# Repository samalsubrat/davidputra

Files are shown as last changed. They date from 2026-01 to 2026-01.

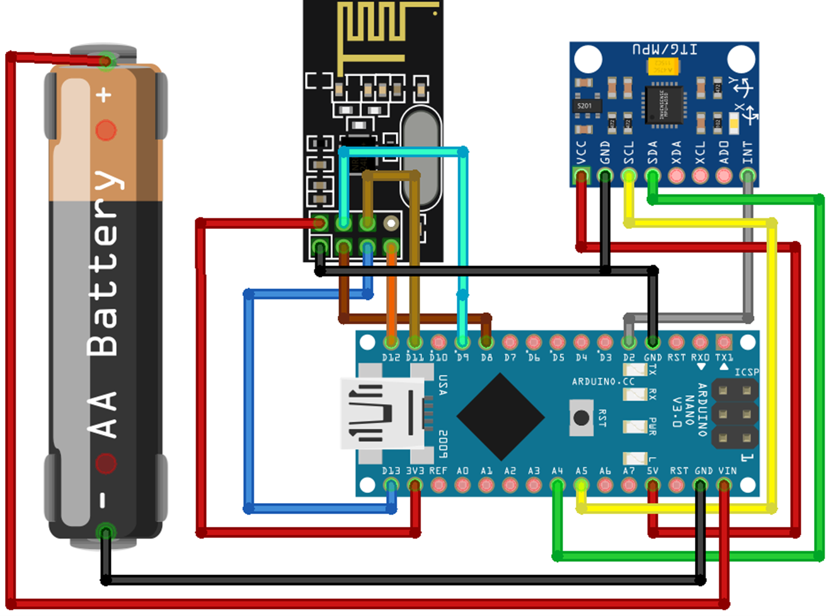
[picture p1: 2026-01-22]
Circuit Diagram/Transmitter.png

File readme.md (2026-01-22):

# Smart Wireless Robotic Vehicle 🚗🤖

A smart Arduino-based robotic vehicle that integrates **gesture control**, **mobile control**, **obstacle detection**, and **automotive-style LED feedback** using wireless communication and embedded systems.

---

## 📌 Project Overview

This project demonstrates a **smart wireless robotic vehicle** controlled using:
- A **gesture-based transmitter**
- **Bluetooth mobile control**
- Real-time **obstacle-aware safety logic**
- Dynamic **NeoPixel LED lighting effects**

The system is inspired by modern automotive behavior, focusing on **safety, responsiveness, and visual feedback**.

---

## 🧠 System Architecture

The project consists of two main units:

### 1️⃣ Transmitter Unit
- Arduino Nano
- MPU6050 (gesture sensing)
- NRF24L01 (wireless transmission)

### 2️⃣ Receiver Unit
- Arduino Uno
- NRF24L01 (wireless reception)
- HC-05 Bluetooth module (mobile control)
- TB6612FNG motor driver
- Ultrasonic sensor (HC-SR04)
- NeoPixel RGB LED strip

---

## ⚙️ Key Features

- Gesture-based control using MPU6050
- Mobile phone control via Bluetooth
- Dual wireless input (NRF + Bluetooth)
- Obstacle-aware forward movement
- Free backward and turning motion
- Automotive-style LED indicators
- RGB flowing effect during reverse
- Non-blocking real-time operation

---

## 🚦 Control Logic

| Command | Action |
|---|---|
| `W` | Move Forward |
| `S` | Move Backward |
| `A` | Turn Left |
| `D` | Turn Right |
| `X` | Stop |

- Obstacle detection is applied **only during forward movement**
- Backward motion is always allowed

---

## 💡 Lighting Behavior (NeoPixel)

- **White center LEDs** → Normal operation
- **Orange sliding indicators** → Left / Right turns
- **RGB flowing effect** → Backward movement
- **All LEDs OFF** → Stop state

---

## 🛡️ Safety Mechanism

- Front-mounted ultrasonic sensor continuously measures distance
- Automatically stops the vehicle when an obstacle is detected in front
- Prevents collision without blocking reverse or turning actions

---

## 🔧 Technologies Used

- Arduino Uno & Nano
- C / C++ (Arduino framework)
- NRF24L01 Wireless Module
- HC-05 Bluetooth Module
- MPU6050 Sensor
- HC-SR04 Ultrasonic Sensor
- TB6612FNG Motor Driver
- Adafruit NeoPixel Library

---

## 🚀 Applications

- Smart robotics
- Gesture-controlled systems
- Autonomous vehicle prototypes
- Embedded systems learning
- Automotive electronics simulation

---

## 🔮 Future Enhancements

- Rear obstacle detection
- Mobile app-based UI
- Brake and hazard lighting logic
- Speed-based LED animations
- ESP32-based implementation

---

## 🎥 Project Demonstration Video

📽️ **Watch the complete working demo here:**  
👉 *[Click Here](https://youtu.be/7BjSHVF1QDA)*

Figma Link: [Click Here](https://www.figma.com/design/feEBxf5zE0kvkO5WWOrKDI/David-Putra-Presentation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)

---

## 🙌 Acknowledgements

This project was developed as part of an academic embedded systems and robotics initiative, demonstrating real-time control, sensing, and wireless communication.

---

## 📬 Contact

For questions or collaboration, feel free to reach out.

---

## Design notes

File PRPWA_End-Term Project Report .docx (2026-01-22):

Project Title

End-Term Project Report

For

Practical Robotics Projects with Arduino (CSE 4571)

Submitted by

Subrat Samal | 2241019269
Saswat Sharma | 2241019415
Shashwat Sahoo | 2241019128
Arvind Naik | 2241014005
Abhinandana Sahoo | 2241019022
Bikash Mallick | 2241013070

B. Tech. 7th Semester, CSE

Project Supervisor

Dr. Hara Prasad Tripathy | (Associate Professor/Assistant Professor)

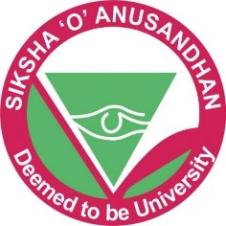
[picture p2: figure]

DEPARTMENT OF COMPUTER SCIENCE AND ENGINEERING

Institute of Technical Education and Research

SIKSHA ‘O’ ANUSANDHAN DEEMED TO BE UNIVERSITY

Bhubaneswar, Odisha, India.

(January, 2026)

# DECLARATION

We certify that

a. The work contained in this report is original and has been done by us under the guidance of our supervisor.
b. The work has not been submitted to any other Institute for any degree or diploma.
c. We have followed the guidelines provided by the Department in preparing the report.

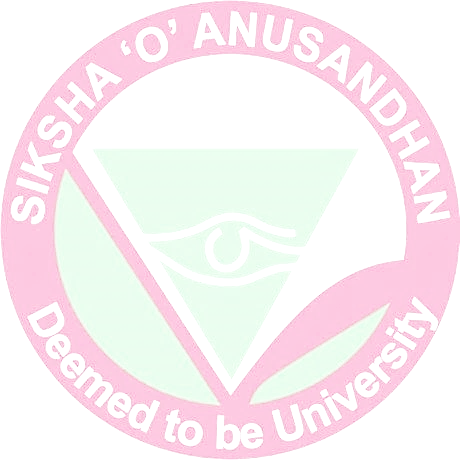
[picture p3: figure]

d. Whenever we have used materials (data, theoretical analysis, figures, and text) from other sources, we have given due credit to them by citing them in the text of the report and giving their details in the reference.

Name of the Student | Registration Number | Signature
Subrat Samal | 2241019269
Arvind Naik | 2241014005
Shashwat Sahoo | 2241019128
Saswat Sharma | 2241019415
Abhinandana Sahoo | 2241019022
Bikash Mallick | 2241013070

# REPORT APPROVAL

The report entitled

TITLE OF THE PROJECT

by

Subrat Samal | 2241019269
Arvind Naik | 2241014005
Shashwat Sahoo | 2241019128
Saswat Sharma | 2241019415
Abhinandana Sahoo | 2241019022
Bikash Mallick | 2241013070

is approved for

Practical Robotics Projects with Arduino (CSE 4571)

in

Computer Science and Engineering

Supervisor’s Name
Date:
Place:

# CONTENTS

# ABSTRACT

This project presents the design and development of a Gesture Controlled Robot Car using Arduino, integrating embedded systems, wireless communication, and human–robot interaction. The system is built around an Arduino Uno microcontroller that controls a four-wheel-drive robotic vehicle capable of responding to real-time gesture-based commands. Wireless communication is achieved using the NRF24L01 module, while obstacle detection is handled by ultrasonic sensors to enhance safety and autonomy.

The robotic car employs a TB6612FNG motor driver for efficient motor control and NeoPixel LEDs for visual feedback. Gesture inputs captured through sensors are translated into movement commands such as forward, backward, left, right, and stop. This project demonstrates an intuitive and user-friendly approach to controlling robotic vehicles and highlights the growing importance of intelligent and interactive robotic systems in modern applications.

# Chapter 1: Introduction

### 1.1. Motivation

With rapid advancements in robotics and embedded systems, there is a growing demand for intelligent machines capable of interacting naturally with humans. Gesture-controlled systems provide an intuitive alternative to conventional control mechanisms such as switches or joysticks. This project is motivated by the need to develop an interactive robotic vehicle that combines gesture control, wireless communication, and autonomous sensing to improve usability and responsiveness.

### 1.2. Design Goals

#### 1.2.1 Purpose

The purpose of this project is to design and implement a gesture-controlled robotic car that can be wirelessly operated and perform basic autonomous functions such as obstacle detection.

#### 1.2.2 Scope

The scope of the project includes embedded control using Arduino, wireless data transmission, real-time motor control, and sensor-based obstacle avoidance.

#### 1.2.3 Applicability

Such robotic systems can be applied in areas like surveillance, defense, warehouse automation, research, and educational robotics.

### 1.3. Problem Statement

Traditional robotic vehicles often rely on manual controls or fixed programming logic, limiting their adaptability and ease of use. The lack of intuitive human–robot interaction makes them unsuitable for dynamic environments. This project addresses this limitation by introducing gesture-based wireless control, enabling real-time, flexible, and user-friendly operation.

### 1.4. Organization of the Report

This report is organized into nine chapters covering introduction, literature survey, design scheme, testing, socio-economic aspects, tools and standards, challenges, teamwork, and conclusions.

# Chapter 2: Literature Survey

### 2.1. Background work done so far

Previous research in mobile robotics has focused on joystick-controlled, Bluetooth-controlled, or autonomous robotic cars. Gesture-controlled robotics has emerged as an advanced method of interaction, offering hands-free and natural control. Studies show that combining wireless communication with sensor-based autonomy significantly improves robot efficiency and safety. However, many existing systems are either costly or complex, motivating the development of a low-cost Arduino-based solution.

# Chapter 3: Design Scheme

### 3.1. System Design

The system consists of a gesture input unit, wireless communication module, Arduino-based control unit, motor driver circuit, ultrasonic sensors, and visual feedback components.

### 3.2. Architecture

Gesture data is captured and transmitted wirelessly to the robotic car. The Arduino Uno processes the received commands and controls the motors accordingly while continuously monitoring obstacle distance using ultrasonic sensors.

### 3.3. Component Design

· Arduino Uno: Central controller

· Arduino Nano: Transmitter controller

· TB6612FNG Motor Driver: Controls motor direction and speed

· DC BO Motors & Wheels: Enable vehicle movement

· HC-SR04 Ultrasonic Sensor: Obstacle detection

· NRF24L01 Module: Wireless communication

· NeoPixel LEDs: Visual status indication

### 3.4. Implementation

The system is implemented using embedded C/C++ programming on Arduino. Gesture commands are mapped to predefined motor actions. Sensor data is continuously monitored to ensure obstacle avoidance.

### 3.5. Design Evolution

Initially designed as a simple remote-controlled car, the system evolved to include gesture recognition, wireless control, visual feedback, and autonomous obstacle detection.

# Chapter 4: Testing, Analysis, and Evaluation

### 4.1. Testing Criterions

4.1.1. Relevance

The functionality of each module was tested to verify that it performs the intended task. Input and output behavior was checked to confirm correct responses under expected conditions. The system’s output was compared with the expected results to ensure accuracy. Real-world use cases were simulated to validate practical applicability.

4.1.2. Effectiveness

The system was tested for correct operations and response accuracy. We conducted multiple test runs to ensure consistent behavior. We checked sensor readings and actuator responses for precision. Wireless communication is stable, and obstacle detection works reliably within defined distance thresholds.

4.1.3. Efficiency

Execution time of the system was measured. Memory and processing utilization were checked. The motor driver ensures efficient power usage, and the system operates smoothly with minimal latency.

# Chapter 5: Socio-Economic Issues associated with the Project

### 5.1. Detailed Cost Analysis

#### 5.1.1. Cost Analysis

The project is designed using low-cost, readily available components. Maintenance cost is low because of the modular design. The system is budget-friendly for students and small-scale users.

#### 5.1.2. Bill of Materials

COMPONENT APPROX COST Arduino Uno Rs 250 Arduino Nano Rs 200 TB6612FNG Rs 200 DC Geared motors Rs 300 Wheels Rs 200 18650 Batteries Rs 240 Battery Holder Rs 50 NRF24L01 HC-SR04 Rs 250 Rs 120 | COMPONENT APPROX COST MPU6050 Rs 180 HC-05 Rs 220 WS2812B NeoPixel Light Rs 300 3D printed Chasis Rs 550 Wires & Other Parts Rs 1000 Total Rs 4060

### 5.2. Safety issues

Low-voltage operation ensures user safety. We used proper insulation to prevent short circuits. We tested moving parts to avoid mechanical hazards. We avoided overcurrent and overheating conditions. Obstacle detection and controlled motor speed reduce the risk of collision and hardware damage.

### 5.3. Global Impact

Gesture-controlled robotics can improve automation, reduce human effort, and support innovation in smart systems globally. It encourages uses of embedded system and robotics. It can also be scaled for industrial, healthcare, or environmental applications.

### 5.4. Lifelong Learning

The project enhances hands-on learning in embedded systems, robotics, wireless communication. It improves problem-solving and debugging skills. It encourages self-learning and innovation and promotes continuous learning as well as skill development.

# Chapter 6: Engineering Tools and Standards used in the Project

• Arduino IDE

• Visual Studio Code

• Fusion 360

• Embedded C/C++

• Standard electronic components

• IEEE standards for wireless communication (NRF24L01)

# Chapter 7: Problems, faults, bugs, challenges

### 7.1. Problems

### Initially there was difficulty in understanding how components connect and interact. Power supply was unstable during early testing. There were integration issues between hardware and software modules. Time constraints occurred during implementation.

### 7.2. Faults

The pin configuration was incorrect in the early stages. Loose connections were causing intermittent failures. There were errors in sensor calibration.

### 7.3. Bugs

There were logical errors in program flow. Incorrect delay timings affected system response. Code synchronization issues occurred between transmitter and receiver.

### 7.4. Challenges

It was challenging to synchronize multiple components without problems, achieving stable and reliable connections between transmitter and receiver. Integrating gesture control with real-time obstacle avoidance also proved to be a hard task.

# Chapter 8: Teamwork

### 8.1. Summary of team work

### 8.1.1 Attributes

1 | Attends group meetings regularly and arrives on time.
2 | Contributes meaningfully to group discussions.
3 | Completes group assignments on time.
4 | Prepares work in a quality manner.
5 | Demonstrates a cooperative and supportive attitude.
6 | Contributes significantly to the success of the project.

### 8.1.2 Score

1=strongly disagree; 2=disagree; 3=agree; 4=strongly agree

Student 1: _________________ Student 2: _________________

Student 3: _________________ Student 4: _________________

Student 5: _________________ Student 6: _________________

Student 1 | Evaluated by
| Attributes | Student 1
| 1
| 2
| 3
| 4
| 5
| 6
| Grand Total

Student 2 | Evaluated by
| Attributes | Student 2
| 1
| 2
| 3
| 4
| 5
| 6
| Grand Total

Signature of Student 1 | | Signature of Student 2

# Chapter 8: Teamwork

Student 1 | Evaluated by
| Attributes | Student 3
| 1
| 2
| 3
| 4
| 5
| 6
| Grand Total

Student 2 | Evaluated by
| Attributes | Student 4
| 1
| 2
| 3
| 4
| 5
| 6
| Grand Total

Signature of Student 3 | | Signature of Student 4

Student 1 | Evaluated by
| Attributes | Student 5
| 1
| 2
| 3
| 4
| 5
| 6
| Grand Total

Student 2 | Evaluated by
| Attributes | Student 6
| 1
| 2
| 3
| 4
| 5
| 6
| Grand Total

Signature of Student 5 | | Signature of Student 6

# Chapter 9: Conclusion

The Gesture Controlled Robot Car successfully demonstrates a gesture-based transmitter using Arduino Nano, MPU6050, and NRF24L01 to generate intuitive control commands. The project also demonstrates the practical application of theoretical concepts learned during the course. The project was designed, implemented and tested systematically to meet stated objectives.

Throughout the development process, careful attention was given to system design, component selection, and implementation. All major modules functions as intended and the system meets the required performance standards.

The project also considers key social and economic factors like cost effectiveness, safety, and global impact. By using low-cost and readily available components, the system is economically viable. Safety measures were included to guarantee secure operation and the project positively contributes to technological development and automation.

In conclusion, the project fulfills its objectives by combining gesture-based control, obstacle detection, and embedded automation. It provides a strong foundation for future enhancements such as AI-based navigation and advanced gesture recognition.

# References

[1] Ian Goodfellow, Jean Pouget-Abadie, Mehdi Mirza, Bing Xu, David Warde-Farley, Sherjil Ozair, Aaron Courville, and Yoshua Bengio. Generative adversarial nets. In Z. Ghahramani, M. Welling, C. Cortes, N. D. Lawrence, and K. Q. Weinberger, editors, Advances in Neural Information Processing Systems 27, pages 2672{2680. Curran Associates, Inc., 2022. URL http://papers.nips.cc/paper/5423-generative-adversarial-nets.pdf

# Appendix

• Circuit connections

• Source code

• Additional test results

• Bill of Materials: https://docs.google.com/spreadsheets/d/1gfLWkVbYy9ZIcscaKPQqSDvCIqm1ycbmBt-wKWR98AM/edit?usp=sharing

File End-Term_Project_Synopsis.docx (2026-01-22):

Group No. | Group Members (Regd. No.) | Project Title
12 | 2241019269 | David Putra - Gesture Controlled Robot Car Using Arduino
| 2241014005
| 2241019128
| 2241019415
| 2241013070
| 2241019022

Fill up the following Topics and submit the colour printed Hardcopy to the corresponding Faculties.

1. Introduction: (Details about the Topic, industry, products, need of study and some history about the same etc.)

This project entails the construction of a 4WD robotic car that integrates embedded systems and modern wireless communication to achieve intelligent mobile robotics behavior. With the growing demand for autonomous and remotely controlled systems, such robotic platforms are increasingly relevant in applications such as autonomous vehicles, logistics, military operations, and research. This project focuses on the integration of mobile robotic systems at the control level of a robotic vehicle, demonstrating the vehicle’s responsive behavior and user interactivity.

The robotic car uses an Arduino Uno microcontroller as its central control unit. The microcontroller performs control functions for the car’s hardware, including motor control through a TB6612FNG motor driver and autonomous obstacle detection using an HC-SR04 ultrasonic sensor. The robotic car also features a NeoPixel LED strip to provide visual feedback and an NRF24L01 wireless module to enable wireless communication.

A key feature of this project is the gesture control system, which allows the user to control the robotic car through hand gestures. These gestures are captured and translated into control commands such as “move forward,” “turn left,” or “stop.” The commands are transmitted wirelessly to the microcontroller, which then executes the corresponding actions, enabling real-time remote control and intuitive interaction with the robotic vehicle.

The research initiated to fulfill the demand for intelligent, autonomous, and human-interactive systems in robotics.

2. Problem identification and Problem Formulation: (Core area of problems or other related problems and their brief solutions)

Conventional robotic vehicles can either be driven manually or have their actions determined through preset logic, resulting in limited flexibility and reduced human interaction. Since these systems lack intuitive control mechanisms, they are less effective in dynamic and real-time environments. The principal challenge lies in achieving responsive and user-friendly control of embedded robotic systems. This project addresses the challenge using an Arduino-based control system combined with a gesture-controlled wireless interface, allowing the user to command the robotic vehicle to move, avoid obstacles, and respond effectively in real time. This approach enhances human–robot interaction while maintaining reliable and efficient embedded control.

3. Objective of the Project: (Objectives should be mentioned pointwise. Students can also divide the broader and narrow areas of the objectives. These objectives must be near to the situation of the problems)
- To design and build a 4WD robotic car using Arduino and essential hardware components.
- To implement autonomous obstacle detection using the HC-SR04 sensor.
- To add AI control through an Android app that understands voice/text commands.
- To enable wireless communication using the NRF24L01 module.
- To control the car's movement using the TB6612FNG motor driver.
- To provide visual feedback using a NeoPixel LED strip.
- To develop a user-interactive robotic system that responds to natural commands.
4. Block Diagram of the Project: (Diagram of a system in which the principal parts or functions are represented by blocks connected by lines that show the relationships of the blocks)

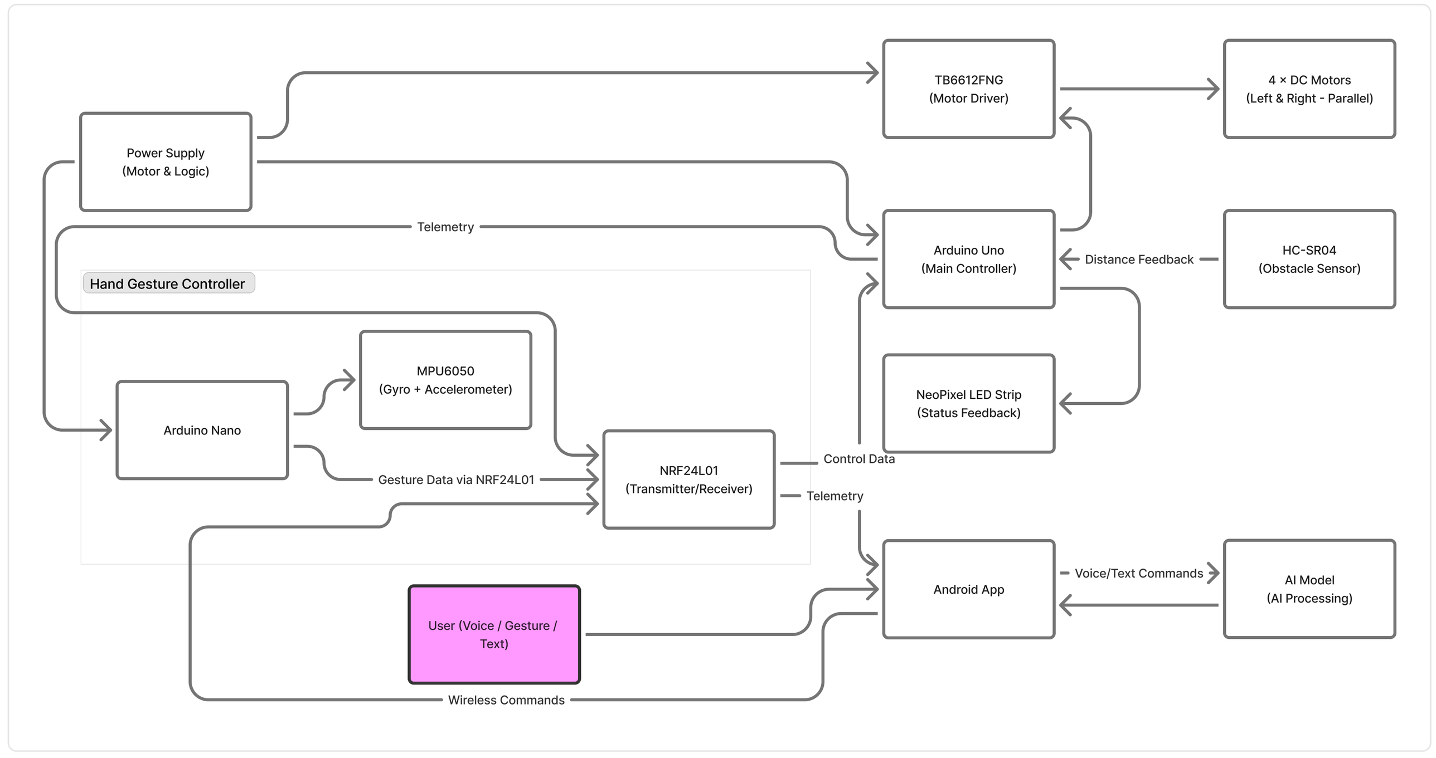
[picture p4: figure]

5. Circuit Diagram of the project:

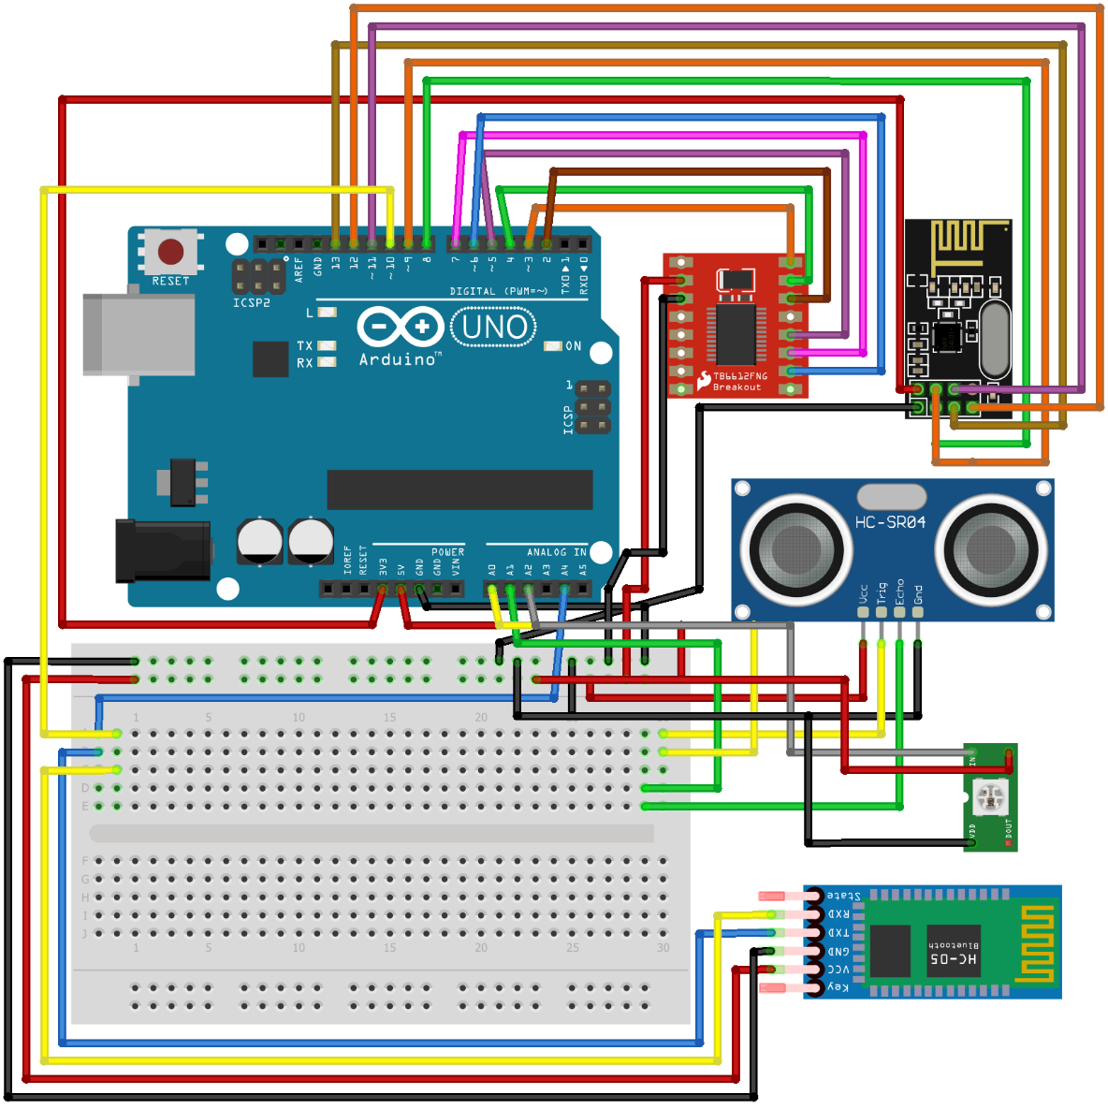
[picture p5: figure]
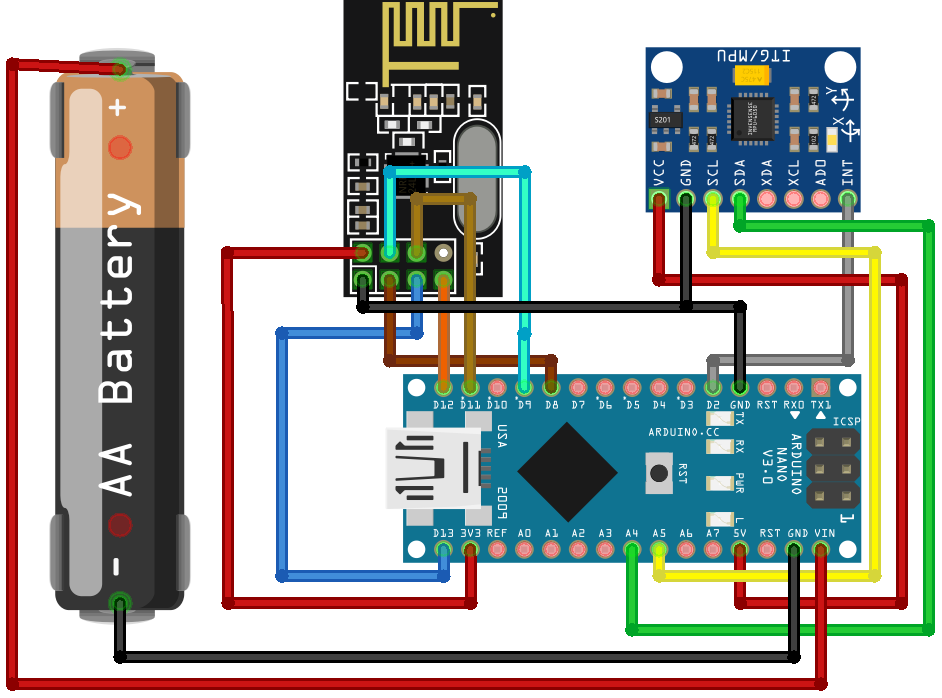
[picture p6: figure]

6. Components/Items Required:

Sl. No. | Name of the Components | Specification | Quantity
1 | Arduino UNO | ATmega328P, 16 MHz | 1
2 | TB6612FNG Motor Driver | Motor Driver Carrier | 1
3 | DC BO Gear Motor | 500 RPM Straight | 4
4 | Wheels | 65mm | 4
5 | Battery | Lipo – 2200mAh-18650 | 3
6 | Battery Holder with Switch | On/Off switch | 2
7 | MPU6050 | Accelerometer + Gyro | 1
8 | Bluetooth Module | HC-05 Module | 1
9 | Arduino Nano | ATmega328P, 16 MHz | 1
10 | Ultrasonic Sensors | HC-SR04 | 2
11 | WiFi Transceiver | NRF24L01 | 2
12 | NeoPixel Lights | WS2812 | 16
13 | Jumper Wires and Accessories | Connecting | -

The project synopsis should be verified by the corresponding faculties within 7 days.

Signature of Corresponding Faculty

Full Signature of Group members:

1.

2.

3.

4.

5.

6.

Practical Robotics Projects with Arduino End-Term Project Synopsis

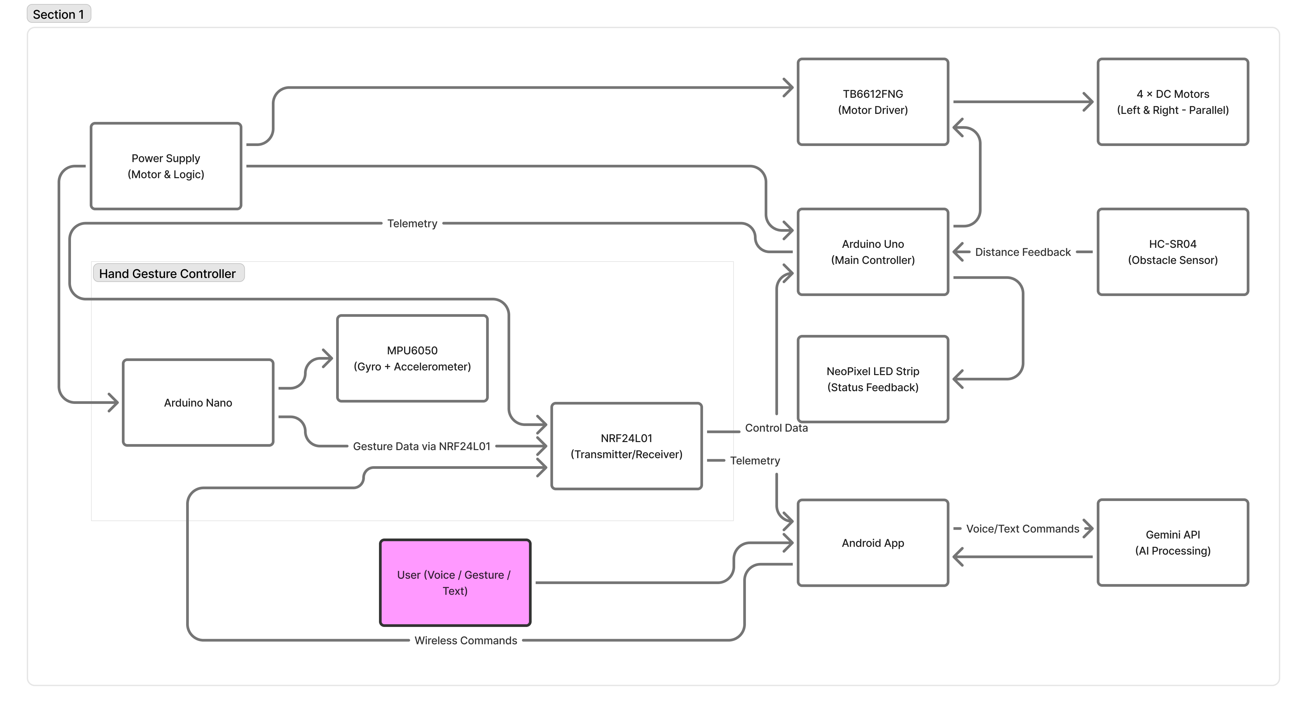
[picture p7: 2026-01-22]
Circuit Diagram/Block Diagram.png

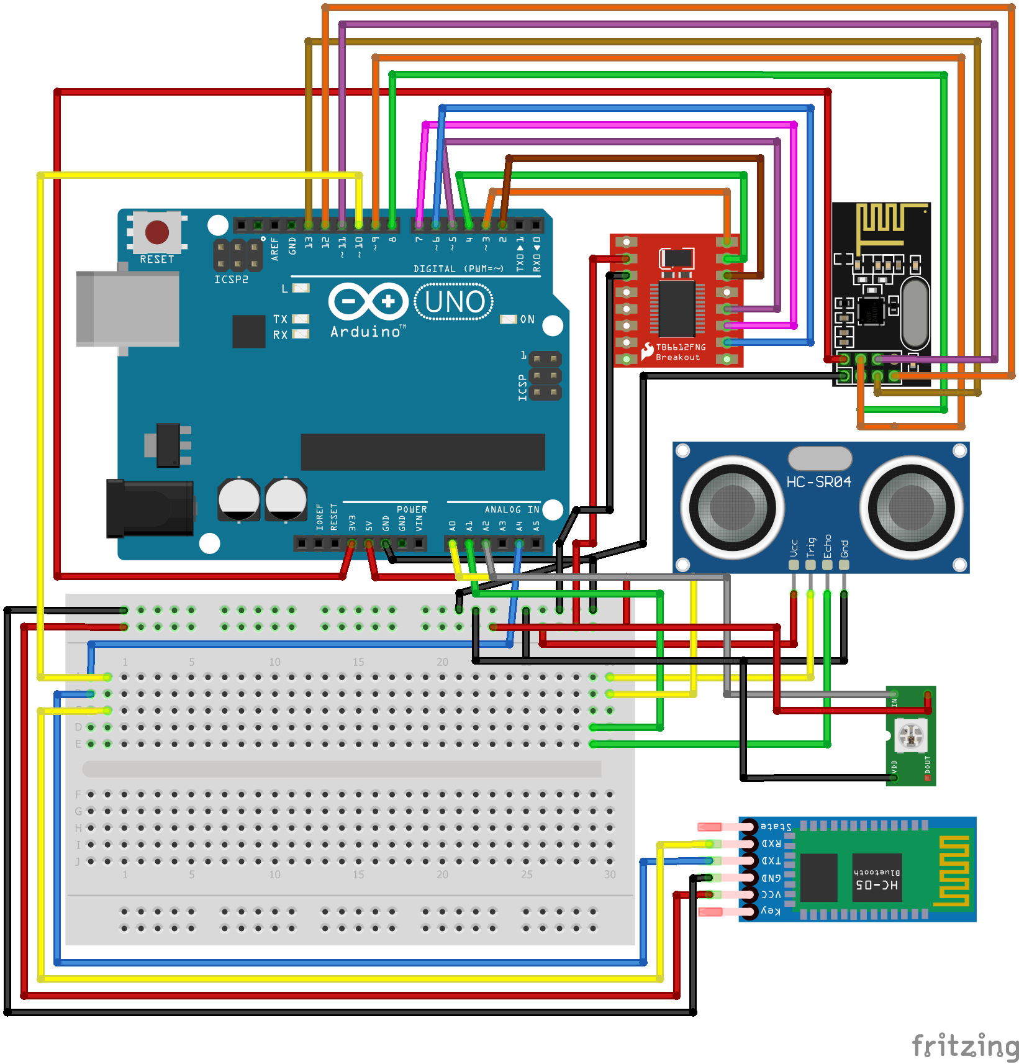
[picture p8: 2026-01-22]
Circuit Diagram/receiver_bb.png

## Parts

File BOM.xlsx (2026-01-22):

Component | Qty | Description / Notes | Price (INR) | Sub Total
Arduino Uno | 1 | Main controller for the car | 250 | 250
TB6612FNG Motor Driver | 1 | Dual motor driver (4 BO motors via both channels) | 165 | 165
500 RPM DC BO GEAR MOTOR STRAIGHT | 4 | DC gear motors (cheap & lightweight) | 75 | 300
Wheels (65mm or 70mm) | 4 | Compatible with BO motors | 25 | 100
Hongli 2200mAh 18650 | 3 | 7.4V–11.1V supply for motors and Uno | 80 | 240
Battery Holder with Switch | 2 | Power management | 50 | 100
MPU6050 or MPU9250 | 1 | Accelerometer + Gyro (gesture input) | 200 | 200
HC-05 Bluetooth Module (for car) | 1 | Bluetooth receiver for control | 250 | 250
Arduino Nano(for glove/controller) | 1 | Processes MPU6050 and sends gestures | 200 | 200
HC-05 Bluetooth Module (for glove) | 1 | Sends control data to car | 250 | 250
Glove | 1 | To mount MPU6050 for gesture input | 50 | 50
Jumper Wires / Connectors / Header Pins | 1 | For connections and soldering | 100 | 100
Breadboard / Custom PCB | 1 | For organized wiring | 100 | 100
HC-SR04 | 4 | UltraSonic Sensor | 60 | 240
PAM8403 Amp | 1 | Amplifier for the speaker | 35 | 35
Speaker | 1 | For AI | 40 | 40
NeoPixel Lights | 2 | Aesthetics | 150 | 300
Camera Module OV7670 | 1 | Camera | 169 | 169
NRF24L01 | 2 | Wireless Stuff | 100 | 200
3D Printing | 1 | Chasis | 550 | 550
Other stuff | 1 | Capacitors, resistors | 200 | 200
 |  | Total |  | 4039

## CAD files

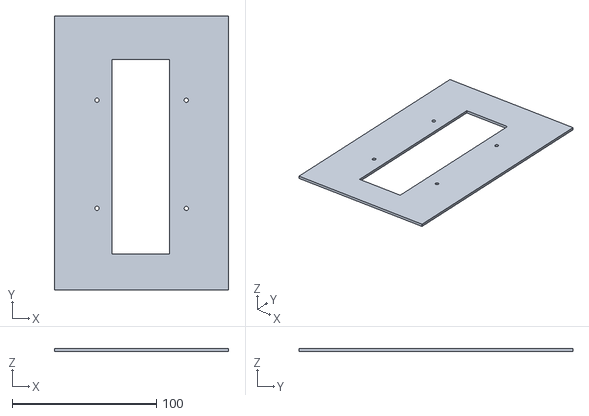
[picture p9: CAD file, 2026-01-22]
3d Files/Chassis bottom.stl
121.0 x 190.0 x 2.00

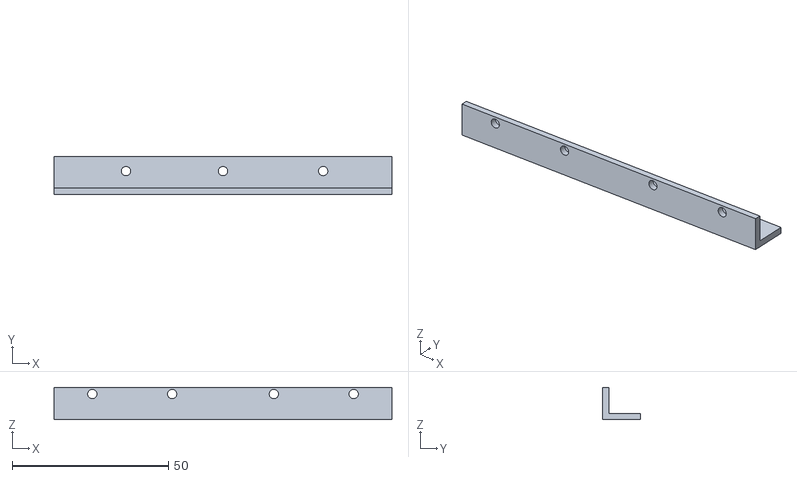
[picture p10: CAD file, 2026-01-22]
3d Files/light bracket.stl
108.0 x 12.0 x 10.4

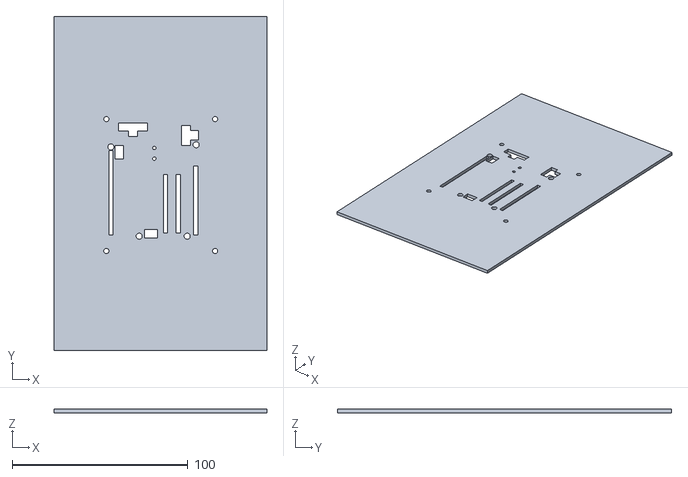
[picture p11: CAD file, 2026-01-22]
3d Files/Chassis top.stl
121.0 x 190.0 x 2.00

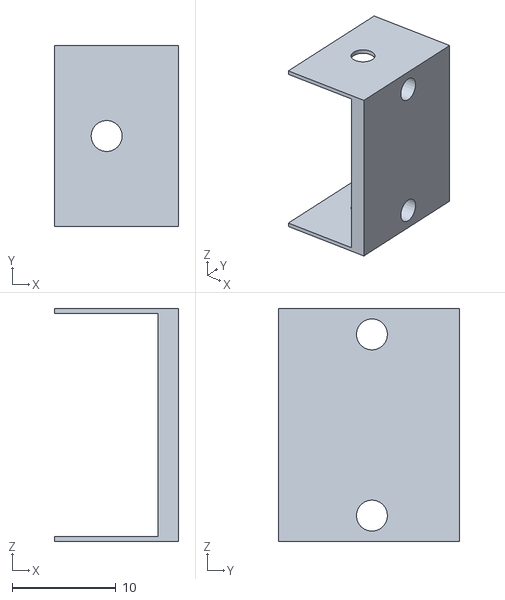
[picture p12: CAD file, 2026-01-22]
3d Files/motor holder.stl
12.0 x 17.4 x 22.5

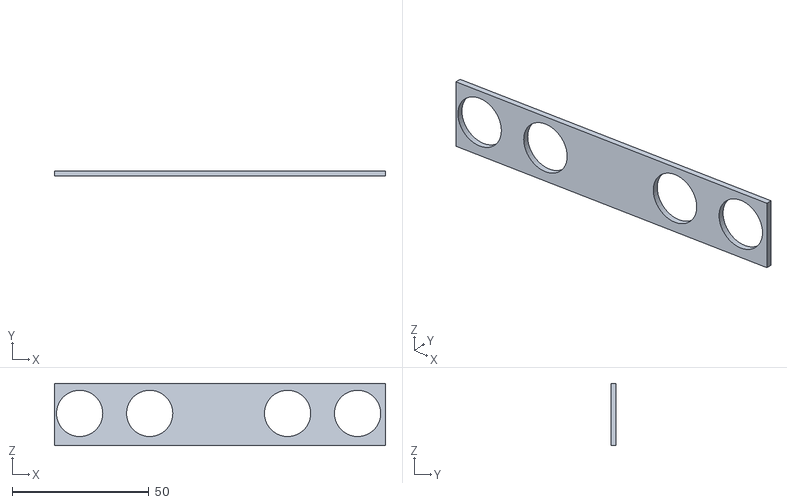
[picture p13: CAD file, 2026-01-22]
3d Files/ultrasonic holder.stl
121.0 x 2.00 x 22.8

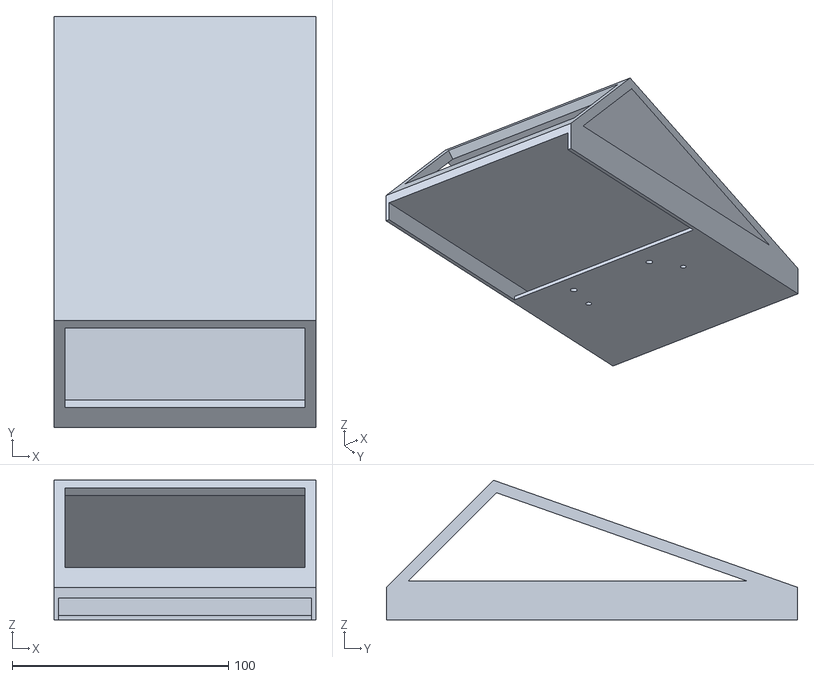
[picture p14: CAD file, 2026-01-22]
3d Files/Top Frame.stl
121.0 x 190.0 x 64.5

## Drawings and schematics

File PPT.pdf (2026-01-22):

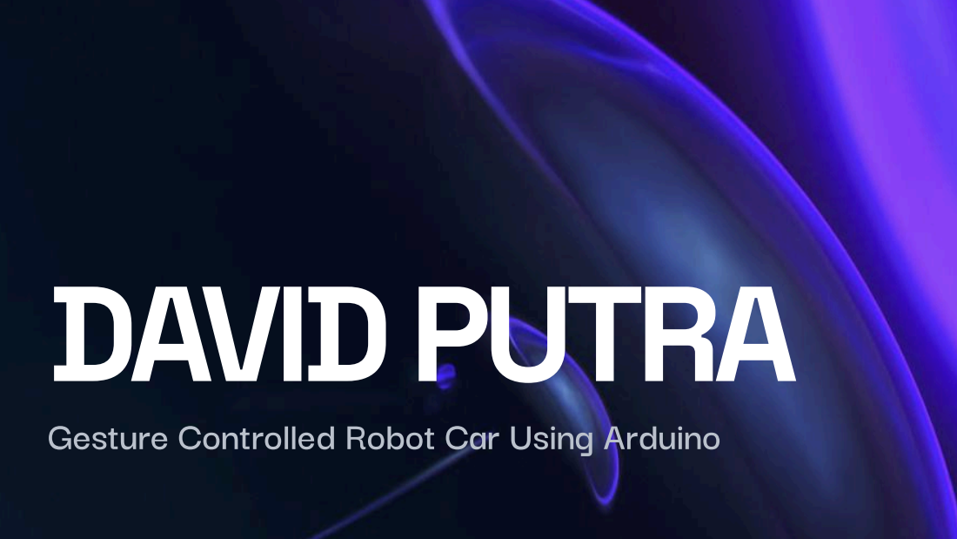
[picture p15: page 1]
David putra

Gesture Controlled Robot Car Using Arduino

# THE

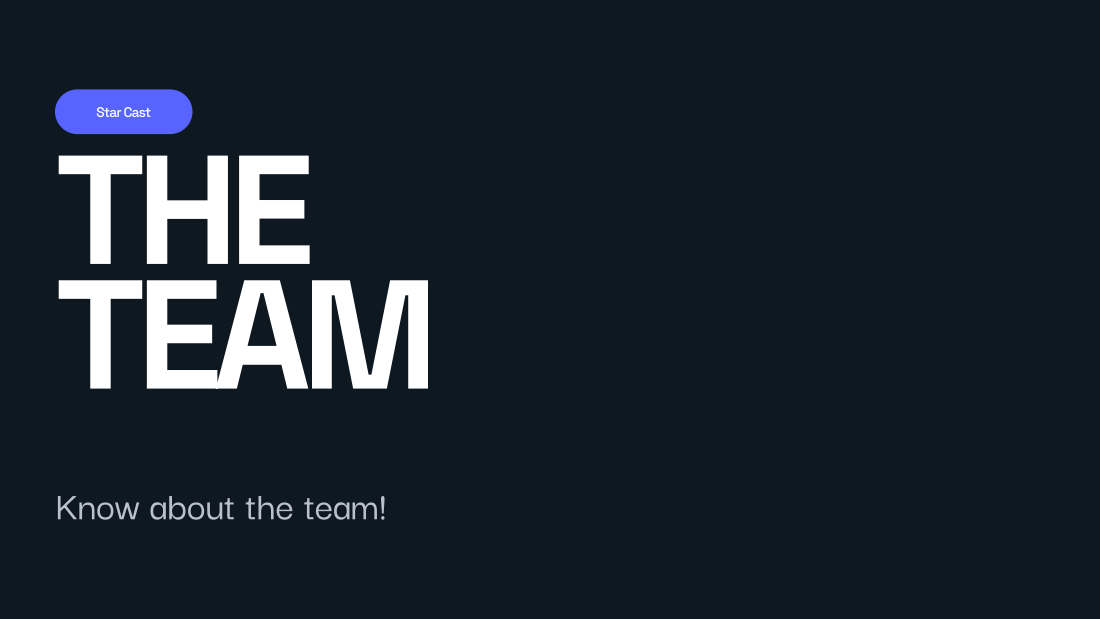
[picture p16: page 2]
Star Cast TEAM

Know about the team!

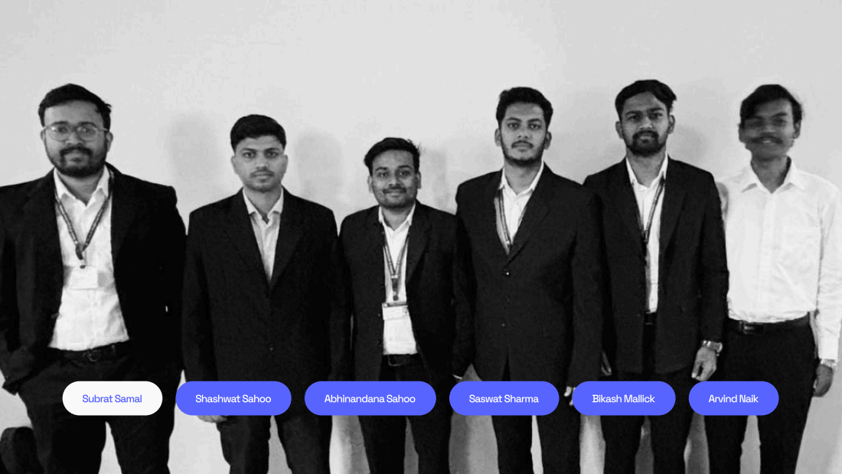
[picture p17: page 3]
Subrat Samal; Shashwat Sahoo; Abhinandana Sahoo; Saswat Sharma; Bikash Mallick; Arvind Naik

# A little more about us

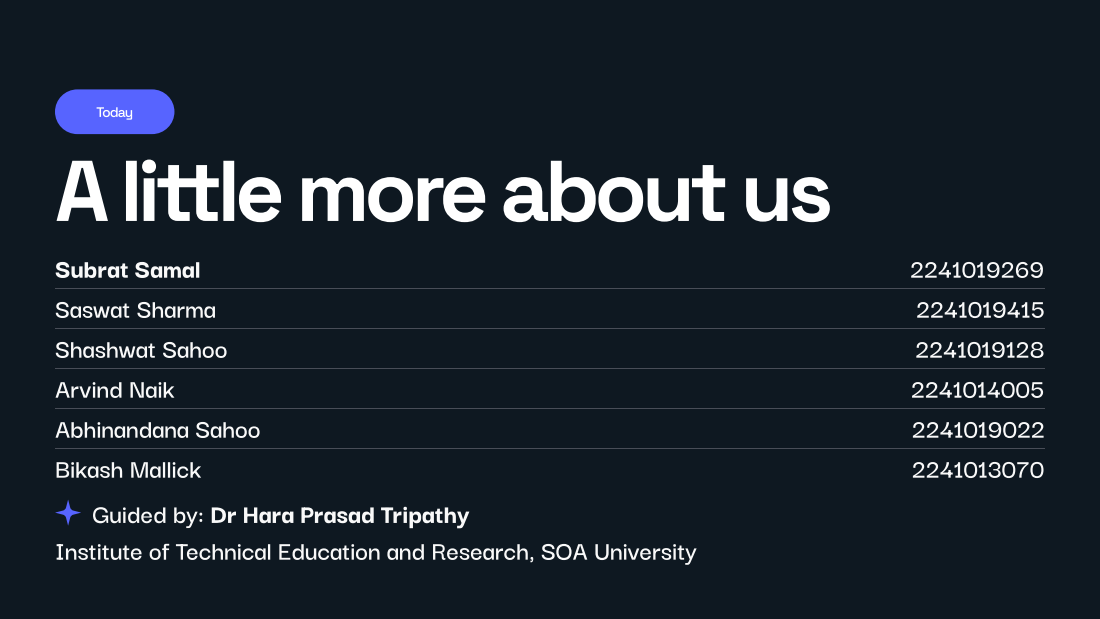
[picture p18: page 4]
Today; Subrat Samal; Saswat Sharma; Shashwat Sahoo; Arvind Naik; Abhinandana Sahoo; Bikash Mallick

Guided by: Dr Hara Prasad Tripathy

Institute of Technical Education and Research, SOA University

### Introduction

# THE

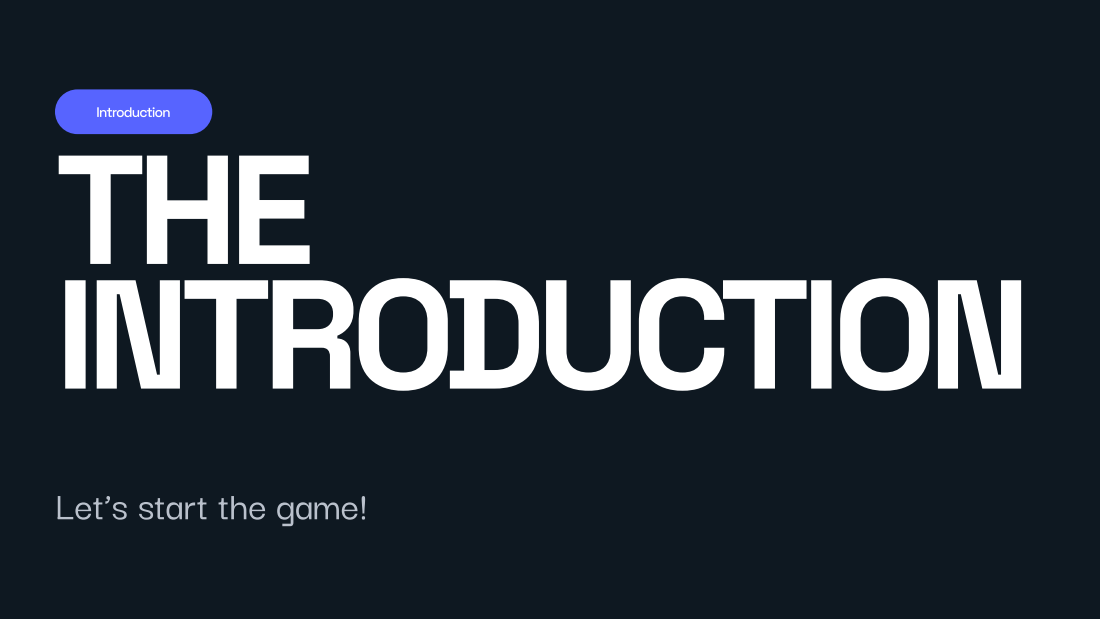
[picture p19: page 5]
INTRODUCTION

Let’s start the game!

Introduction

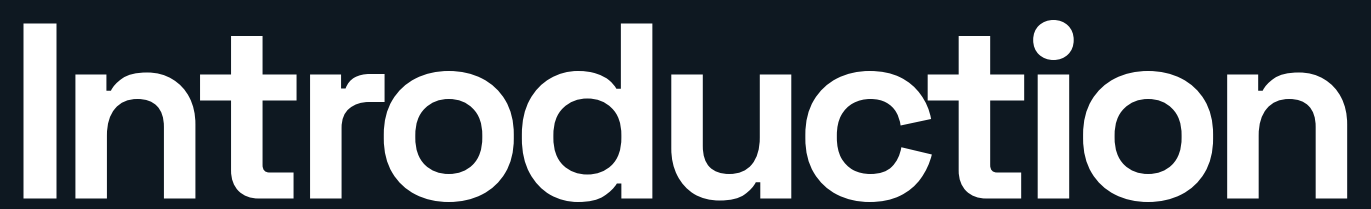
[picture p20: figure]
Introduction

This project is a smart wireless robotic vehicle designed using a Arduino Uno & a Arduino Nano, integrating wireless

control, obstacle awareness, motor driving, and intelligent LED signaling.

The system combines NRF24L01 radio communication, Bluetooth control, a TB6612FNG motor driver, an ultrasonic

distance sensor, and NeoPixel RGB LEDs to create a feature-rich and responsive robotic platform.

The entire system operates using non-blocking logic, ensuring smooth motor control, responsive wireless communication,

and stable LED animations without delays.

Overall, this project demonstrates the integration of embedded systems, wireless communication, sensor-based safety,

and visual feedback, making it a strong example of a real-world robotic control system inspired by modern

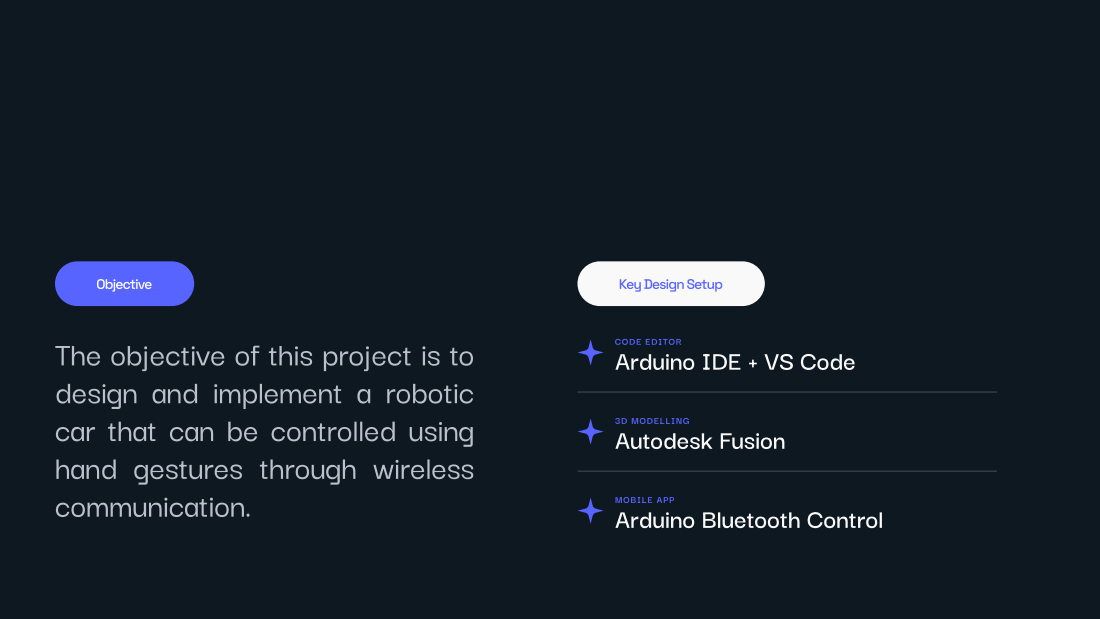
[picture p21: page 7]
Objective

Key Design Setup

CODE EDITOR Arduino IDE + VS Code

The objective of this project is to
design and implement a robotic
car that can be controlled using
hand gestures through wireless
communication.

3D MODELLING Autodesk Fusion

MOBILE APP Arduino Bluetooth Control

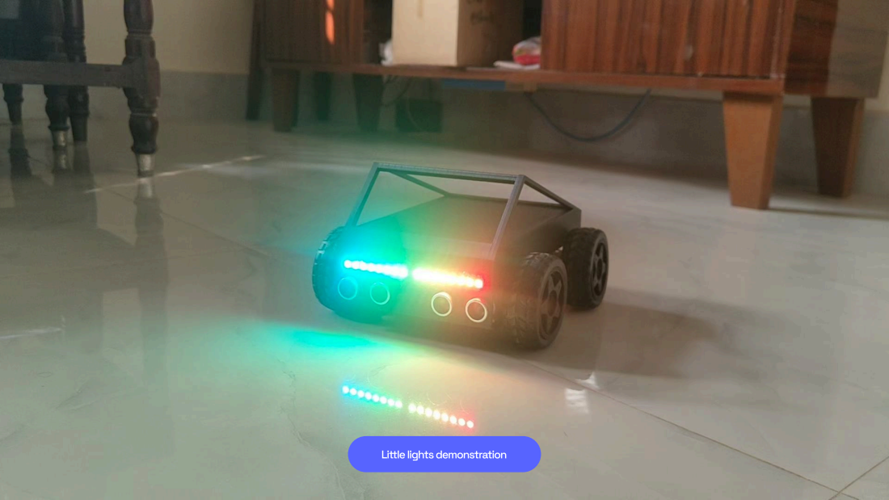
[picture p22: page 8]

Little lights demonstration

# Working

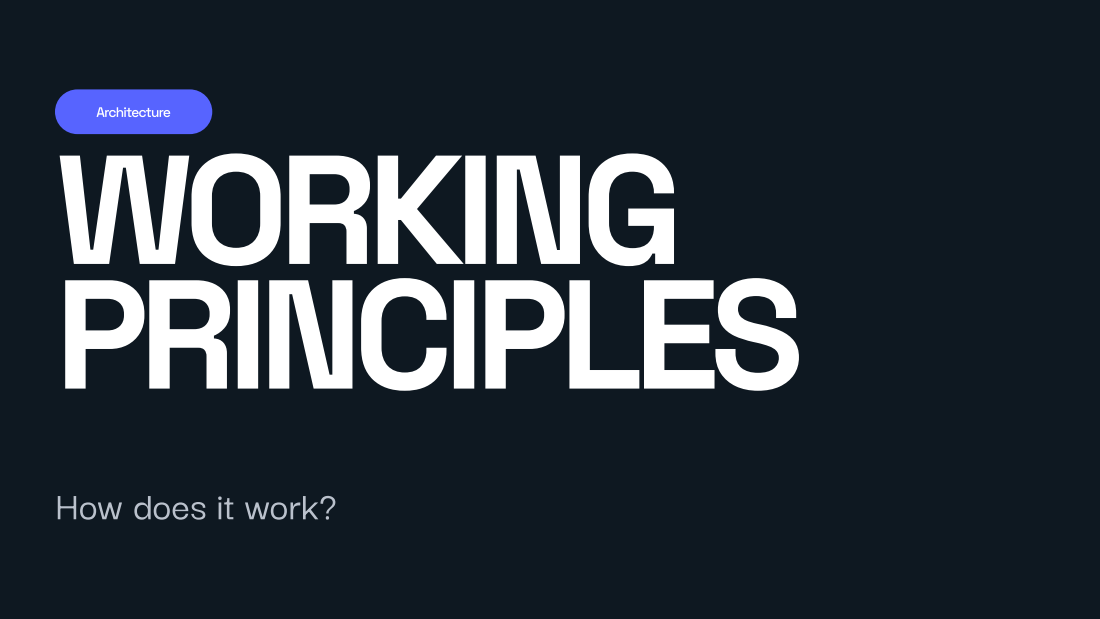
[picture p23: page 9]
Architecture principles

How does it work?

## Architecture

# The system consists of two main sections:

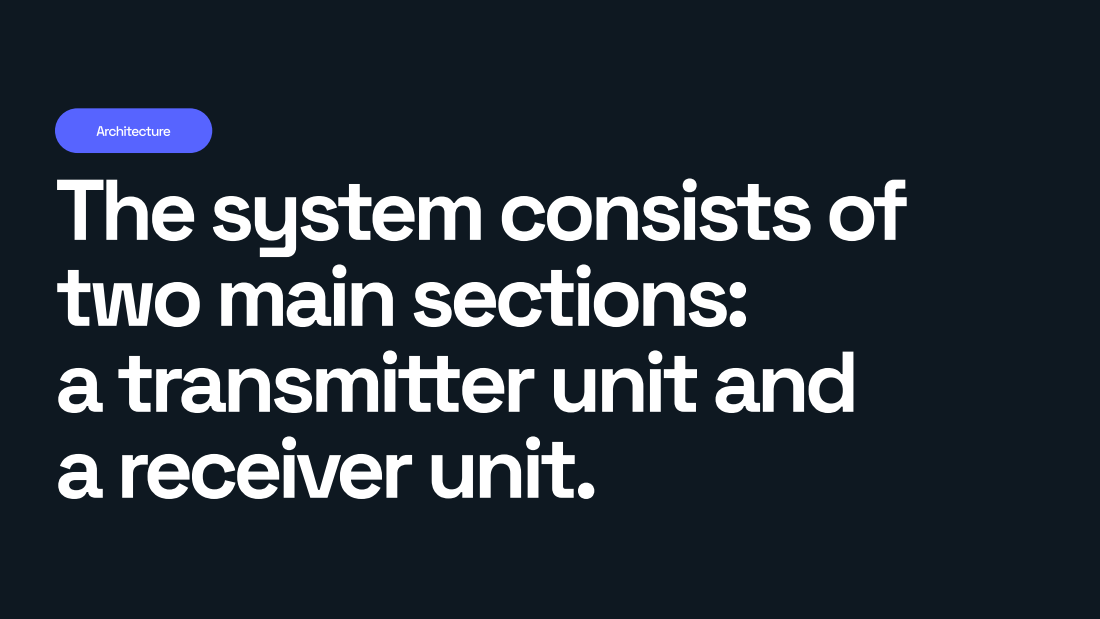
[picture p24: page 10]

a transmitter unit and a receiver unit.

Architecture

# Transmitter

The transmitter unit acts as the gesture controller. It consists of an Arduino Nano, an MPU6050 accelerometer and

gyroscope sensor, and an NRF24L01 wireless transceiver.

The MPU6050 continuously measures acceleration and angular velocity along multiple axes to capture real-time hand

orientation. Raw sensor data is filtered and mapped into directional commands such as forward, backward, left, and right.

The Arduino Nano converts motion thresholds into discrete control signals, reducing noise and unintended movements.

Encoded control commands are transmitted at low latency using the NRF24L01 module for responsive vehicle control.

Wireless communication is optimized for short-range, reliable transmission with minimal packet loss. The transmitter

operates in a non-blocking loop, ensuring smooth gesture tracking and consistent data updates.

# The remote // Transmitter

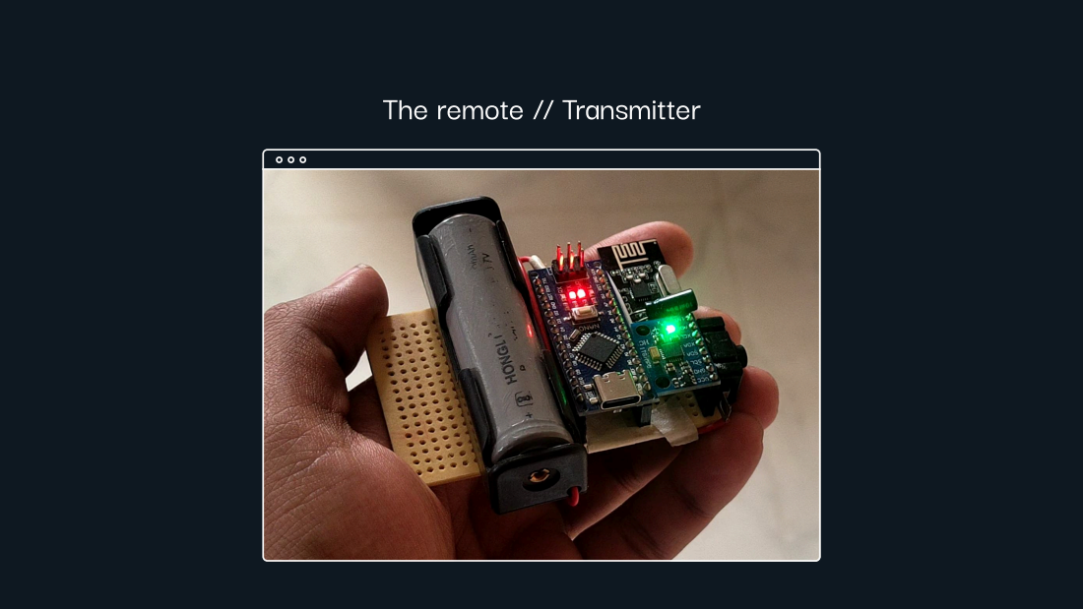
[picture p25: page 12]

Architecture

# Receiver

The receiver unit is based on an Arduino Uno, interfaced with an NRF24L01 wireless module to receive control commands

In addition to NRF communication, an HC-05 Bluetooth module enables direct mobile phone control, allowing flexible

The Arduino interprets received commands and generates appropriate motor control signals for forward, backward, left,

A TB6612FNG motor driver converts control signals into efficient motor operation with adjustable speed and direction.

The motor driver is connected to a 7.4V external battery to run the four geared DC motors.

Architecture

# Receiver

A front-mounted ultrasonic sensor provides obstacle detection, automatically preventing forward movement when an

object is detected. This increases safety of the robot car.

NeoPixel RGB LEDs provide real-time visual feedback, reflecting vehicle state through indicators and motion-based lighting effects. It also makes the whole car more attractive.

The receiver operates using non-blocking logic, ensuring smooth motor response, stable wireless communication, and

# The robot car // Receiver

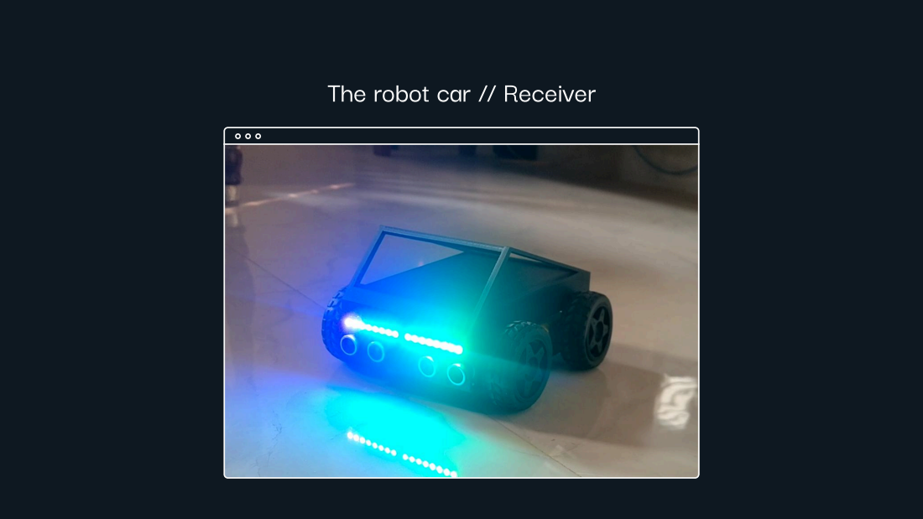
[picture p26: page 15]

# Know

much more!

This document doesn’t cover the entire project in details, for that please head over to:
github/samalsubrat/davidputra (https://github.com/samalsubrat/davidputra)


Architecture
Circuit Diagrams
of the entire system!

# Receiver Circuit Diagram

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

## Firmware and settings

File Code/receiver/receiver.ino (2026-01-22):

#include <SPI.h>
#include <nRF24L01.h>
#include <RF24.h>
#include <SoftwareSerial.h>
#include <Adafruit_NeoPixel.h>

// ================= NRF24 =================
RF24 radio(9, 10);  // CE, CSN
const byte address[6] = "00001";

// ================= Bluetooth =================
SoftwareSerial bt(A3, A2);  // RX, TX (Arduino side)

// ================= NeoPixel =================
#define LED_PIN A4
#define LED_COUNT 16
Adafruit_NeoPixel strip(LED_COUNT, LED_PIN, NEO_GRB + NEO_KHZ800);

// ================= TB6612 =================
#define AIN1 2
#define AIN2 4
#define PWMA 3
#define BIN1 7
#define BIN2 6
#define PWMB 5
#define STBY 8

// ================= HC-SR04 =================
#define TRIG_PIN A0
#define ECHO_PIN A1

// ================= Config =================
int speedVal = 130;

unsigned long lastPacketTime = 0;
const unsigned long NRF_TIMEOUT = 1500;

const int OBSTACLE_DISTANCE = 20;  // cm
unsigned long lastUltrasonicTime = 0;
const unsigned long ULTRASONIC_INTERVAL = 60;

bool obstacleDetected = false;
char lastMoveCmd = 'x';

// ================= Robot State =================
enum State { STOP,
             FORWARD,
             BACKWARD,
             LEFT,
             RIGHT };
State currentState = STOP;

// ================= NeoPixel Animation =================
unsigned long lastAnimationTime = 0;
int animationStep = 0;
const int animationSpeed = 200;

uint32_t colorWhite;
uint32_t colorYellow;
uint32_t colorOrange;

uint8_t rgbHue = 0;
unsigned long lastRGBTime = 0;
const unsigned long RGB_INTERVAL = 20;  // lower = smoother

uint32_t wheel(byte pos) {
  pos = 255 - pos;
  if (pos < 85) {
    return strip.Color(255 - pos * 3, 0, pos * 3);
  }
  if (pos < 170) {
    pos -= 85;
    return strip.Color(0, pos * 3, 255 - pos * 3);
  }
  pos -= 170;
  return strip.Color(pos * 3, 255 - pos * 3, 0);
}


// ================= Setup =================
void setup() {
  Serial.begin(9600);
  bt.begin(9600);

  // NeoPixel init
  strip.begin();
  strip.setBrightness(150);
  strip.show();

  colorWhite = strip.Color(255, 255, 255);
  colorYellow = strip.Color(255, 200, 0);
  colorOrange = strip.Color(255, 92, 0);

  pinMode(AIN1, OUTPUT);
  pinMode(AIN2, OUTPUT);
  pinMode(PWMA, OUTPUT);
  pinMode(BIN1, OUTPUT);
  pinMode(BIN2, OUTPUT);
  pinMode(PWMB, OUTPUT);
  pinMode(STBY, OUTPUT);

  pinMode(TRIG_PIN, OUTPUT);
  pinMode(ECHO_PIN, INPUT);

  digitalWrite(STBY, HIGH);
  stopMotors();

  initNRF();
}

// ================= NRF =================
void initNRF() {
  radio.begin();
  radio.setPALevel(RF24_PA_MIN);
  radio.setDataRate(RF24_250KBPS);
  radio.openReadingPipe(1, address);
  radio.startListening();
}

void recoverNRF() {
  radio.stopListening();
  radio.powerDown();
  delay(5);
  radio.powerUp();
  delay(5);
  initNRF();
}

// ================= Ultrasonic =================
long getDistanceCM() {
  digitalWrite(TRIG_PIN, LOW);
  delayMicroseconds(2);
  digitalWrite(TRIG_PIN, HIGH);
  delayMicroseconds(10);
  digitalWrite(TRIG_PIN, LOW);

  long duration = pulseIn(ECHO_PIN, HIGH, 25000);
  if (duration == 0) return 999;
  return duration / 58;
}

// ================= Motor Control =================
void stopMotors() {
  analogWrite(PWMA, 0);
  analogWrite(PWMB, 0);
  currentState = STOP;
}

void left() {
  digitalWrite(AIN1, HIGH);
  digitalWrite(AIN2, LOW);
  digitalWrite(BIN1, HIGH);
  digitalWrite(BIN2, LOW);
  analogWrite(PWMA, speedVal);
  analogWrite(PWMB, speedVal);
  currentState = LEFT;
}

void right() {
  digitalWrite(AIN1, LOW);
  digitalWrite(AIN2, HIGH);
  digitalWrite(BIN1, LOW);
  digitalWrite(BIN2, HIGH);
  analogWrite(PWMA, speedVal);
  analogWrite(PWMB, speedVal);
  currentState = RIGHT;
}

void forward() {
  digitalWrite(AIN1, LOW);
  digitalWrite(AIN2, HIGH);
  digitalWrite(BIN1, HIGH);
  digitalWrite(BIN2, LOW);
  analogWrite(PWMA, speedVal);
  analogWrite(PWMB, speedVal);
  currentState = FORWARD;
}

void backward() {
  digitalWrite(AIN1, HIGH);
  digitalWrite(AIN2, LOW);
  digitalWrite(BIN1, LOW);
  digitalWrite(BIN2, HIGH);
  analogWrite(PWMA, speedVal);
  analogWrite(PWMB, speedVal);
  currentState = BACKWARD;
}

// ================= Command Handler =================
void handleCommand(char cmd) {

  if (cmd == 'w' || cmd == 'a' || cmd == 's' || cmd == 'd') {
    lastMoveCmd = cmd;
  }

  lastPacketTime = millis();

  // Block ONLY forward when obstacle is detected
  if (obstacleDetected && cmd == 'w') return;


  switch (cmd) {
    case 'd': right(); break;
    case 'a': left(); break;
    case 'w': forward(); break;
    case 's': backward(); break;
    case 'x': stopMotors(); break;

    case '1': speedVal = 80; break;
    case '2': speedVal = 150; break;
    case '3': speedVal = 255; break;
  }
}

// ================= NeoPixel Update =================
void updateNeoPixels() {
  unsigned long now = millis();

  strip.setPixelColor(3, colorWhite);
  strip.setPixelColor(4, colorWhite);
  strip.setPixelColor(5, colorWhite);
  strip.setPixelColor(6, colorWhite);
  strip.setPixelColor(7, colorWhite);
  strip.setPixelColor(8, colorWhite);
  strip.setPixelColor(9, colorWhite);
  strip.setPixelColor(10, colorWhite);
  strip.setPixelColor(11, colorWhite);
  strip.setPixelColor(12, colorWhite);

  switch (currentState) {

    case FORWARD:
      strip.fill(colorWhite);
      strip.show();
      break;

    case BACKWARD:
      if (now - lastRGBTime > RGB_INTERVAL) {
        lastRGBTime = now;
        rgbHue++;
      }

      for (int i = 0; i < LED_COUNT; i++) {
        // Offset hue per LED to create flow
        strip.setPixelColor(i, wheel(rgbHue + i * 8));
      }

      strip.show();
      break;


    case LEFT:
      if (now - lastAnimationTime > animationSpeed) {
        lastAnimationTime = now;
        animationStep++;
        if (animationStep > 3) {
          animationStep = 0;
          strip.clear();
          strip.setPixelColor(4, colorWhite);
          strip.setPixelColor(5, colorWhite);
          strip.setPixelColor(6, colorWhite);
          strip.setPixelColor(7, colorWhite);
          strip.setPixelColor(8, colorWhite);
          strip.setPixelColor(9, colorWhite);
          strip.setPixelColor(10, colorWhite);
          strip.setPixelColor(11, colorWhite);
          strip.setPixelColor(12, colorWhite);
          ;
        }

        if (animationStep > 0) strip.setPixelColor(3, colorOrange);
        if (animationStep > 0) strip.setPixelColor(2, colorOrange);
        if (animationStep > 1) strip.setPixelColor(1, colorOrange);
        if (animationStep > 2) strip.setPixelColor(0, colorOrange);

        strip.show();
      }
      break;

    case RIGHT:
      if (now - lastAnimationTime > animationSpeed) {
        lastAnimationTime = now;
        animationStep++;
        if (animationStep > 3) {
          animationStep = 0;
          strip.clear();
          strip.setPixelColor(3, colorWhite);
          strip.setPixelColor(4, colorWhite);
          strip.setPixelColor(5, colorWhite);
          strip.setPixelColor(6, colorWhite);
          strip.setPixelColor(7, colorWhite);
          strip.setPixelColor(8, colorWhite);
          strip.setPixelColor(9, colorWhite);
          strip.setPixelColor(10, colorWhite);
          strip.setPixelColor(11, colorWhite);
        }

        if (animationStep > 0) strip.setPixelColor(12, colorOrange);
        if (animationStep > 0) strip.setPixelColor(13, colorOrange);
        if (animationStep > 1) strip.setPixelColor(14, colorOrange);
        if (animationStep > 2) strip.setPixelColor(15, colorOrange);

        strip.show();
      }
      break;

    case STOP:
      strip.clear();
      strip.show();
      break;
  }
}


// ================= Loop =================
void loop() {

  // Ultrasonic
  if (millis() - lastUltrasonicTime > ULTRASONIC_INTERVAL) {
    lastUltrasonicTime = millis();
    long dist = getDistanceCM();

    if (dist < OBSTACLE_DISTANCE && currentState == FORWARD) {
      if (!obstacleDetected) {
        stopMotors();
        obstacleDetected = true;
      }
    } else {
      if (obstacleDetected) {
        obstacleDetected = false;
      }
    }
  }


    // NRF
    if (radio.available()) {
      char cmd;
      radio.read(&cmd, sizeof(cmd));
      handleCommand(cmd);
    }

    // Bluetooth
    if (bt.available()) {
      handleCommand(bt.read());
    }

    // Serial
    if (Serial.available()) {
      handleCommand(Serial.read());
    }

    // NRF failsafe
    if (millis() - lastPacketTime > NRF_TIMEOUT) {
      stopMotors();
      recoverNRF();
      lastPacketTime = millis();
    }

    updateNeoPixels();
  }

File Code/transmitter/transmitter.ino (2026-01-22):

/*
  Gesture Control Transmitter (Complete Version)
  - Uses MPU6050 to detect tilt
  - Sends specific mapped data to Receiver
  - Library Requirements: RF24, I2Cdev, MPU6050
*/

#include <SPI.h>
#include <nRF24L01.h>
#include <RF24.h>
#include <Wire.h>
#include <I2Cdev.h>
#include <MPU6050.h>

// --- MPU6050 Setup ---
MPU6050 mpu;
int16_t ax, ay, az;
int16_t gx, gy, gz;

// --- Data Packet ---
// data[0] = X Axis (Forward/Back)
// data[1] = Y Axis (Left/Right)
int data[2];

// --- NRF24L01 Setup ---
// CE = 8, CSN = 9 (As per your working snippet)
RF24 radio(8, 9); 

// Address (Must match the Receiver exactly)
const uint64_t pipe = 0xE8E8F0F0E1LL;

void setup(void) {
  Serial.begin(9600);
  Wire.begin();
  
  // Initialize MPU6050
  Serial.println("Initializing MPU6050...");
  mpu.initialize();
  
  // Verify MPU connection
  if(mpu.testConnection()) {
    Serial.println("MPU6050 connection successful");
  } else {
    Serial.println("MPU6050 connection failed");
  }

  // Initialize NRF24L01
  radio.begin();
  radio.openWritingPipe(pipe);
  radio.setPALevel(RF24_PA_MIN); // Low power mode (better for battery life/stability)
  radio.stopListening();         // Put radio in Transmitter mode
  
  Serial.println("Transmitter Ready.");
}

void loop(void) {
  // 1. Read Raw Data from MPU6050
  mpu.getMotion6(&ax, &ay, &az, &gx, &gy, &gz);

  // 2. Map and Prepare Data
  // X Axis: Maps raw accel (-17000 to 17000) to range (300 to 400)
  // Center is approx 350. >365 is Forward, <335 is Backward.
  data[0] = map(ax, -17000, 17000, 300, 400); 

  // Y Axis: Maps raw accel (-17000 to 17000) to range (100 to 200)
  // Center is approx 150. >165 is Right, <135 is Left.
  data[1] = map(ay, -17000, 17000, 100, 200);

  // 3. Send Data via NRF
  bool report = radio.write(data, sizeof(data));

  // 4. Debugging (View in Serial Monitor)
  // Only prints if transmission was successful to avoid spamming errors
  if (report) {
    Serial.print("Sent -> X: ");
    Serial.print(data[0]);
    Serial.print(" | Y: ");
    Serial.println(data[1]);
  } else {
    Serial.println("Transmission Failed (Check NRF wiring)");
  }
  
  // Small delay to prevent flooding the radio
  delay(20); 
}
